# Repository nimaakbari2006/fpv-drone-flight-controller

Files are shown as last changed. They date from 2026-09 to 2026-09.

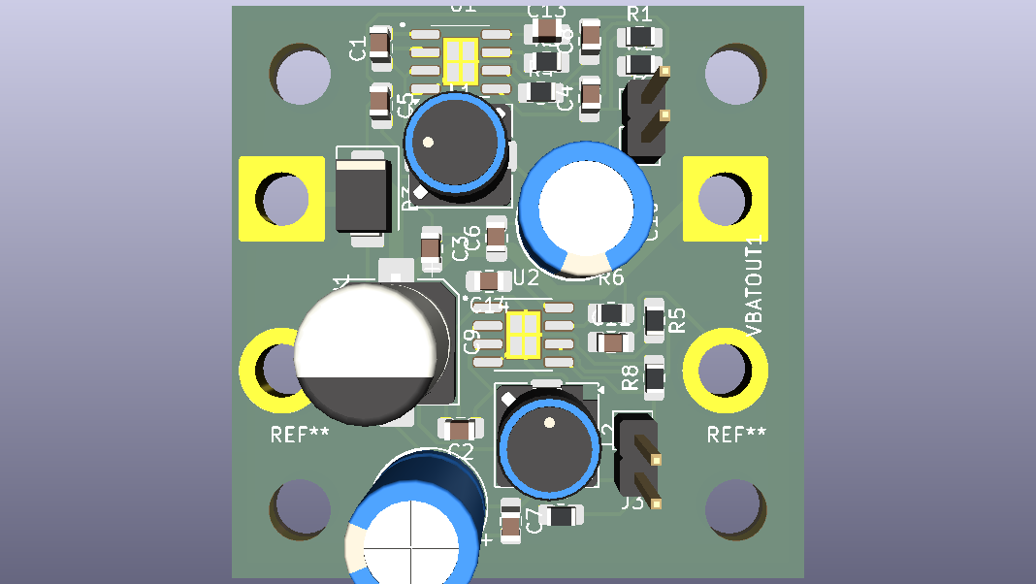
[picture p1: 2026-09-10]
PDB/PDB_layout.png.png

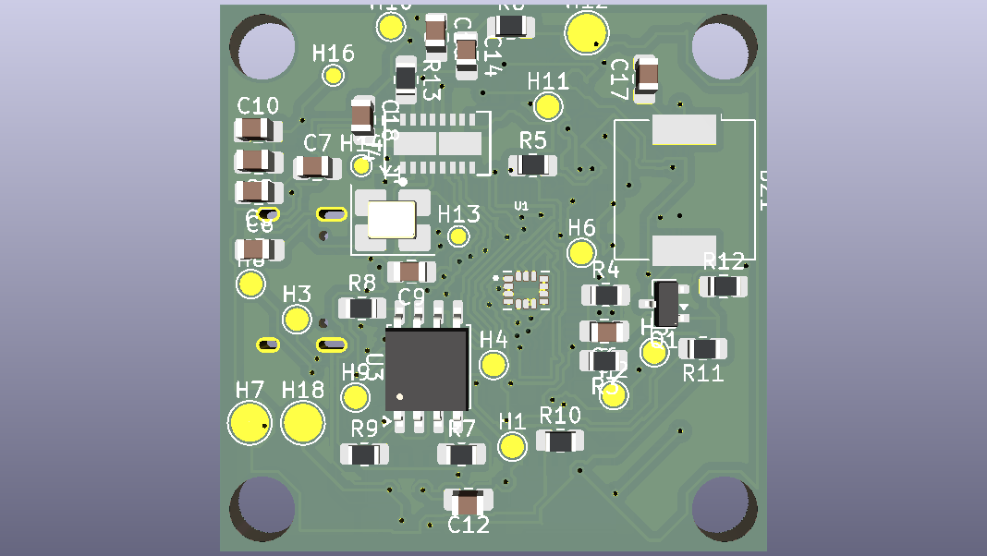
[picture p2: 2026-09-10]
FlightController/FCBOTTOMVIEW.png

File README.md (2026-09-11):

# Custom FPV Drone — Power Distribution Board & Flight Controller

Two custom PCBs designed from scratch in KiCad for a 5-inch FPV drone, plus complete component selection and compatibility validation for the full build. This project covers the full stack: switching power supply design, a Betaflight-compatible flight controller, and systems-level integration of the entire aircraft.

---

## Overview

The goal was to replace the stock electronics of a 5-inch FPV drone with custom-designed hardware, as an electrical engineering portfolio project. Two boards were designed:

1. **Power Distribution Board (PDB)** — takes 4S LiPo battery input and generates regulated 5V and 3.3V rails while distributing raw battery power to the ESC.
2. **Flight Controller (FC)** — an STM32F405-based, Betaflight-compatible flight controller with a full peripheral set.

Both boards were designed to the standard 30.5 × 30.5 mm FPV stack mounting pattern to integrate with the airframe and ESC.

---

## Power Distribution Board

A dual-output switching power supply feeding the drone's electronics.

**Key features:**
- 4S LiPo (up to ~16.8V) input with XT60 connection
- Two synchronous buck converters (MP2307) generating **5V** and **3.3V**
- Input protection: SM6T22A TVS diode against voltage spikes
- Raw battery pass-through (VBATOUT) to the 4-in-1 ESC via wide copper
- Feedback dividers, compensation networks, soft-start, and proper input/output decoupling on each channel

**Design decisions:**
- Chose the **MP2307 synchronous buck** over the older LM2596 after finding that the LM2596's through-hole inductors exceeded the frame's stack-height clearance — a real mechanical constraint that drove the part selection toward a smaller SMD synchronous design.
- Replaced the large through-hole bulk capacitor with an SMD polymer cap to fit the board within the mounting footprint.

*(See `/PDB/` for schematic, layout, 3D render, and Gerbers.)*

---

## Flight Controller

A full-featured, Betaflight-compatible flight controller.

**Core:**
- **STM32F405RGT6** MCU (LQFP-64)
- **ICM-42688-P** gyro/accelerometer over SPI1
- 8 MHz crystal, full power decoupling, VCAP, reset & boot circuitry
- USB-C for configuration and firmware flashing (with CC pulldowns and power-OR Schottky)
- Onboard 3.3V LDO so the board runs from USB alone on the bench

**Peripherals:**
- **AT7456E OSD** for on-screen display over the analog video feed (SPI3)
- **W25Q128 SPI flash** for blackbox flight logging
- 4 motor outputs (DShot-capable timer pins) + ESC telemetry & current sense
- ELRS receiver UART, VTX (SmartAudio) control, GPS UART
- Analog camera input and VTX video output through the OSD
- Battery voltage sensing, buzzer driver, addressable LED output
- SWD debug header

**Design decisions:**
- Followed the official **Betaflight F405 pin mapping** so the board matches an existing firmware target rather than requiring a custom one (gyro on SPI1, OSD/flash sharing SPI3, careful UART assignment to avoid the DFU/USART conflict).
- **4-layer stackup** with a dedicated internal ground plane beneath the IMU for clean gyro readings, and controlled routing of the USB differential pair.

*(See `/FlightController/` for schematic, layout, 3D render, and Gerbers.)*

---

## Circuit Design & Component Selection

The design methodology was datasheet-driven: each IC's manufacturer datasheet specifies a recommended application circuit, and following those recommended values — for decoupling, compensation, loop stability, and support components — is the correct engineering practice rather than guessing or reinventing them. Where the design required application-specific values that the datasheet does not give directly (chiefly the regulator output voltages and the battery-sense scaling), those were calculated from the relevant equations. This section documents both.

### Values sourced from datasheets and reference circuits

The majority of passive values came directly from the manufacturers' recommended application circuits:

- **MCU decoupling** — the STM32F405 datasheet specifies a **100 nF** ceramic at each VDD pin plus a shared bulk capacitor; the **2.2 µF** low-ESR capacitors on the VCAP core-regulator pins are a hard datasheet requirement (the internal core regulator will not start without them).
- **Analog supply filtering** — the **600 Ω @ 100 MHz** ferrite bead plus **1 µF / 100 nF** VDDA filter follows ST's recommended arrangement to keep digital switching noise off the ADC reference.
- **Buck converter support** — the MP2307's loop-compensation R–C network, **10 nF** soft-start capacitor, **10 nF** bootstrap capacitor, and input/output capacitor values were taken from the MP2307 datasheet's typical application circuit for the chosen inductor and output-cap combination.
- **IMU** — the ICM-42688-P's supply decoupling (**2.2 µF + 100 nF**) follows TDK's reference circuit, and its reserved pins were terminated exactly as the datasheet pin-description table specifies.
- **OSD** — the on-screen-display support components and crystal frequency were taken from the OSD device's datasheet and a known-good reference design.

Using the datasheet's recommended circuit is deliberate: manufacturers characterise these values for stability and noise performance, and deviating from them without reason is how power supplies end up oscillating or ICs end up unstable.

### Values calculated for this design

A few values are application-specific and were derived rather than copied:

**Buck converter output voltages (feedback dividers).** The MP2307 servos its feedback pin to an internal 0.925 V reference; the output is set by a divider:

```
Vout = 0.925 V × (1 + Rtop / Rbot)
```

With Rbot fixed at 10 kΩ, Rtop was solved for each rail:
- **5V rail:** Rtop ≈ 44.05 kΩ → nearest E96 value **44.2 kΩ** (gives 5.01 V)
- **3.3V rail:** Rtop ≈ 25.68 kΩ → nearest E96 value **25.5 kΩ** (gives 3.28 V)

1% (E96) resistors were used so output accuracy is set by the reference and divider, not resistor drift.

**Battery voltage sensing.** A **100 kΩ / 10 kΩ** divider scales the raw battery voltage down to the STM32's 3.3 V ADC range: at 4S full charge (16.8 V) the ADC sees ~1.5 V, at 6S (25.2 V) ~2.3 V — both safely under the 3.3 V limit with headroom. This matches Betaflight's default voltage-sensing scale.

**Crystal load capacitors.** Sized from the crystal's specified load capacitance and estimated board stray capacitance using `Cload_cap ≈ 2 × (CL − Cstray)`, giving **~22 pF** per oscillator node.

### Values set by standards

- **5.1 kΩ** pull-downs on the USB-C CC pins — the specific value required by the USB-C specification for a device to advertise itself and draw bus power.
- **75 Ω** termination on the analog video lines — matches the standard 75 Ω video signal impedance.

### Values from standard digital-design practice

Pull-ups and pull-downs were chosen high enough to draw negligible current but low enough to hold a defined logic level against pin leakage — **10 kΩ** for the NRST pull-up, BOOT0/BOOT1 pull-downs, and the SPI flash/OSD chip-select and hold lines; **100 kΩ** for the buzzer MOSFET gate pull-down so it stays off while its GPIO is floating during boot.

---

## Full Drone Build & Component Selection

Beyond the PCBs, the project involved specifying and validating an entire FPV drone, ensuring every component is electrically and mechanically compatible.

**Key selection decisions:**
- **Motors:** iFlight XING 2207 **1800KV** — the correct kV range for a 4S 5-inch freestyle build (higher-kV variants are 2–4S racing parts).
- **Video system:** a fully **analog 5.8GHz** chain — RunCam Robin 3 → JHEMCU VTX20-600 → FlyFishRC Osprey antenna → goggles — with **RHCP** polarization matched from drone to goggles.
- **Control link:** **ELRS 2.4GHz** (RadioMaster Pocket + Nano RX), both on FCC firmware for region compatibility.
- **ESC:** 55A rating, sized comfortably above the motors' ~35A peak draw.

**Interface & connector compatibility** (each verified against the actual component pinouts):
- FC ↔ ESC: 8-pin JST-SH (motor signals, telemetry, current, power)
- FC ↔ Camera: 6-pin JST-SH, wired to the RunCam Robin 3's pinout (power, GND, video, camera control)
- FC ↔ VTX: 4-pin (video, GND, battery, SmartAudio)
- FC ↔ GPS / Receiver: JST-SH UART connectors
- Video RF: MMCX (VTX to antenna), RHCP polarization matched throughout

*(See `/BOM/FPV_Drone_BOM.xlsx` for the complete bill of materials with compatibility notes.)*

---

## Tools & Skills

**KiCad** · schematic capture · PCB layout · 4-layer stackup design · switching power supply design · SPI/UART bus architecture · USB routing · DRC/ERC verification · library management (symbol/footprint import) · datasheet-driven design · systems integration · component selection & compatibility analysis

---

## Status

Both boards are fully designed and verified in KiCad (ERC and DRC clean). Manufacturing files (Gerbers, BOM, placement) generated for fabrication and assembly. Full drone build specified and components sourced.

*Physical assembly and flight testing to follow — this README will be updated with assembly photos and results.*

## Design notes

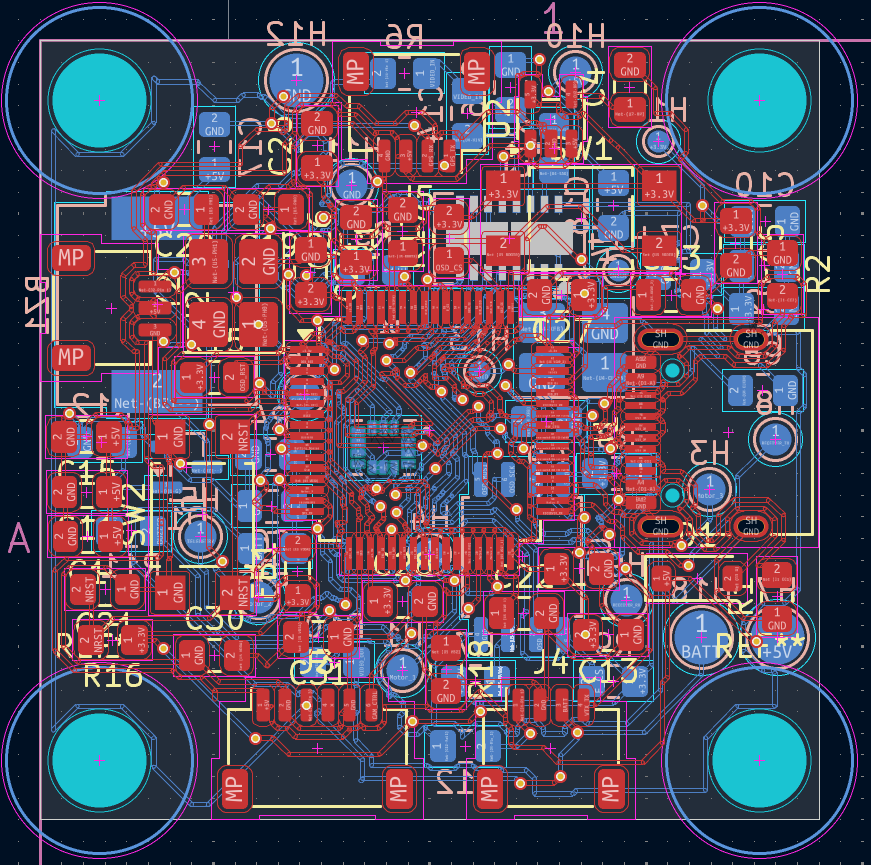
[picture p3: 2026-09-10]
FlightController/PCBLAYOUT.png

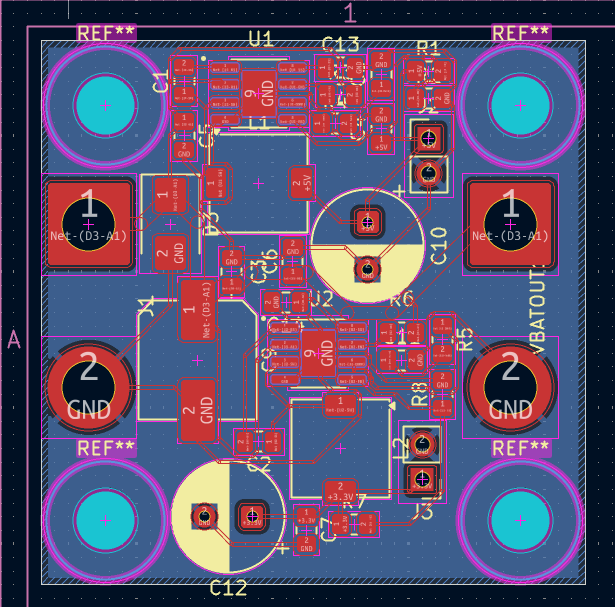
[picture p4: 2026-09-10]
PDB/PCBLAYOUT.png

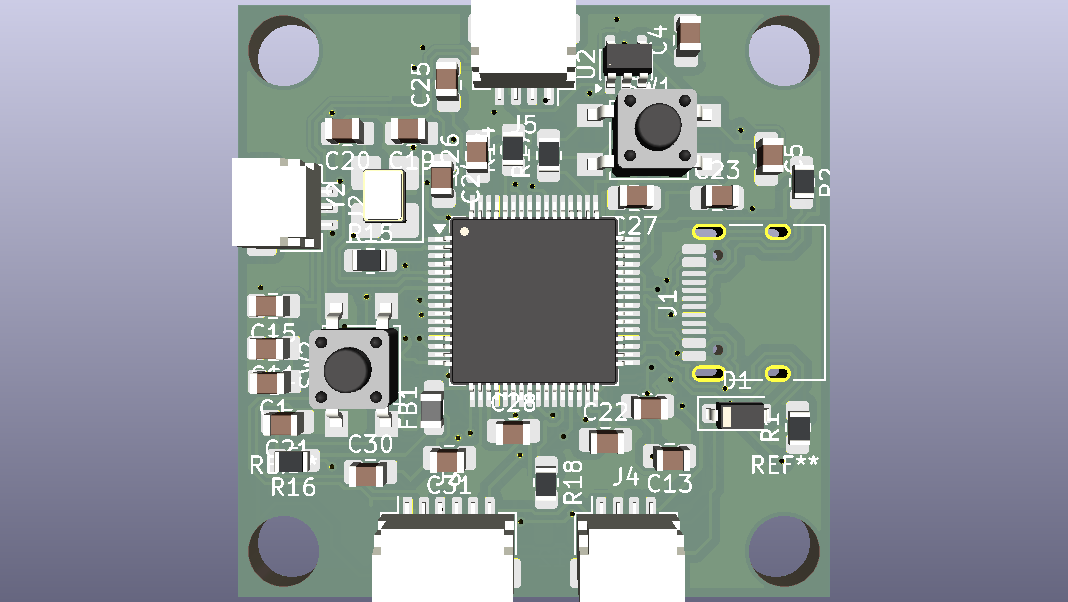
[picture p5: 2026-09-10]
FlightController/FCTOPVIEW.png

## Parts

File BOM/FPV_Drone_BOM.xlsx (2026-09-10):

FPV Drone — Complete Bill of Materials
5-inch Freestyle Build • Mark4 frame • 4S • Analog 5.8GHz FPV • ELRS 2.4GHz • Custom PDB + FC (in development)
MECHANICAL / AIRFRAME
Item | Chosen Part | Key Specs | Qty | Status | Cost (CAD) | Notes / Compatibility
Frame | Mark4 5-inch (REA-Mark-5), Red | 5" props, 2207 motors, 30.5×30.5 stack, 19.3mm cam mount | 1 | TO BUY | $29.82 | Aliexpress (https://www.aliexpress.com/item/1005007889232446.html?scm_id=1007.23125.137358.0&scm-url=1007.23125.137358.0)
Motors | iFlight XING-E Pro 2207 1800KV | 12N14P, 3–6S, 35A max, 16×16 mount | 4 | TO BUY | $82.53 | Aliexpress (https://www.aliexpress.com/item/1005007751330225.html?scm_id=1007.23125.137358.0&scm-url=1007.23125.137358.0)
Propellers | Gemfan 51466 V2 tri-blade, Midnight Gray | 5", M5 shaft, CW+CCW, 2207+ motors | 2 packs | TO BUY | $50.00 | Aliexpress (https://www.aliexpress.com/item/1005006320959638.html?scm_id=1007.23125.137358.0&scm-url=1007.23125.137358.0)
Battery straps | FlyFishRC strap | 20×250mm, metal buckle | 5PK 2SET | TO BUY | $20.00 | Aliexpress (https://www.aliexpress.com/item/1005010398663157.html?curPageLogUid=y0xrC8Tz6n97)
POWER / MOTOR SYSTEM
Item | Chosen Part | Key Specs | Qty | Status | Cost (CAD) | Notes / Compatibility
FC + ESC Stack | DAKEFPV F405 55A Stack | F405 MCU, 55A 4-in-1, 30.5×30.5, BLHeli_S, DShot | 1 | TO BUY | 62.38 | Aliexpress (https://www.aliexpress.com/item/1005012244392227.html?curPageLogUid=BF1mfSOBs0Lg)
↳ incl. 1000µF cap | 35V 1000µF Low-ESR | Battery bulk cap | 1 | TO BUY
↳ incl. cables/hardware | SH cables, grommets, screws, XT60 | FC-ESC cable, soft-mount, 70mm XT60 | set | TO BUY
Battery | Zeee 4S 1500mAh 120C | 14.8V, XT60, 120C, ~177g | 2-pk (+1 existing = 3) | TO BUY | $55.99 | Amazon (https://www.amazon.ca/Zeee-Graphene-Quadcopter-Helicopter-Airplane/dp/B0868RDZZP)
XT60 spares (custom PDB) | XT60 pigtails | For testing your custom PDB later | — | Optional
CONTROL / RADIO LINK
Item | Chosen Part | Key Specs | Qty | Status | Cost (CAD) | Notes / Compatibility
Radio (handset) | RadioMaster Pocket | ELRS 2.4GHz, FCC, Mode 2, EdgeTX | 1 | TO BUY | $136.40 | FCC = correct for Canada; ELRS matches receiver
Receiver | RadioMaster Nano ELRS 2.4GHz | ELRS 2.4GHz, CRSF, 5V | 1 | TO BUY |  | INCLUDED with radio — FCC-matched, no separate buy
↳ incl. 18650 cells | 2× 18650 | Powers the radio | 2 | TO BUY |  | Included in radio bundle
VIDEO SYSTEM — TRANSMIT (on drone)
Item | Chosen Part | Key Specs | Qty | Status | Cost (CAD) | Notes / Compatibility
FPV Camera | RunCam Robin 3 | Analog, 1200TVL, 4:3, 19mm, 5-23V | 1 | TO BUY | $16.08 | Analog; 19mm fits 19.3mm mount; powers from stack
VTX | JHEMCU VTX20-600 | 5.8GHz analog, 40CH, PIT-600mW, MMCX, 5V BEC | 1 | TO BUY | $24.09 | 600mW proper power; MMCX matches antenna
Drone Antenna | FlyFishRC Osprey | 5.8GHz, MMCX, RHCP, 90mm | 1 | TO BUY | $8.93 | MMCX matches VTX; RHCP sets system polarization
VIDEO SYSTEM — RECEIVE (goggles)
Item | Chosen Part | Key Specs | Qty | Status | Cost (CAD) | Notes / Compatibility
FPV Goggles | Mini FPV Goggles (box) | Analog 5.8GHz, 40CH all bands, 3" 480×320, <20ms | 1 | TO BUY | 90.67 | Analog matches system; RP-SMA antennas
Goggle Antennas (upgrade) | RP-SMA RHCP cloverleaf | 5.8GHz, RHCP, RP-SMA | pair | Optional
CHARGING
Item | Chosen Part | Key Specs | Qty | Status | Cost (CAD) | Notes / Compatibility
Charger | iMAX B6 | Balance, 1-6S LiPo, 0.1-6A, 80W | 1 | Ordered | 45.77
Power Supply | 12V 5A AC adapter | 60W, powers the B6 | 1 | Ordered |  | 60W ample for 4S 1500mAh charging
Charge Lead | Banana-to-XT60 lead | Connects battery to charger | 1 | Ordered |  | Required to connect XT60 packs to B6
SAFETY / CONSUMABLES
Item | Chosen Part | Key Specs | Qty | Status | Cost (CAD) | Notes / Compatibility
LiPo Safety Bag | Fireproof LiPo bag | Charge & store LiPos inside | 1 | TO BUY
Spare props | Gemfan 51466 V2 | Restock as you break them | — | Later
CUSTOM PCBs (your resume project — in development)
Item | Chosen Part | Key Specs | Qty | Status | Cost (CAD) | Notes / Compatibility
Custom PDB | Your KiCad design | Dual MP2307 buck, 5V+3.3V, TVS, 40×40mm | 1 | Ordered |  | component ordered
Custom FC | Your KiCad design (F405) | STM32F405, ICM-42688-P, USB-C, OSD, etc. | 1 | Ordered |  | component ordered
PCB fabrication | JLCPCB / PCBWay | 2× boards, ~5 pcs each | — | Ordered |  | component ordered
PCB components | STM32, IMU, MP2307×2, passives | BOM from KiCad | — | TO DO
TOOLS (one-time, for assembly & PCB work)
Item | Chosen Part | Key Specs | Qty | Status | Cost (CAD) | Notes / Compatibility
Soldering iron | Temp-controlled (e.g. Pinecil V2) | For assembly + PCB | 1 | TO BUY
Hot air station | For QFN/fine-pitch (FC assembly) | Needed for IMU/MCU QFN | 1 | TO BUY
Consumables | Solder, flux, wick, tweezers, IPA, microscope | SMD soldering kit | set | TO BUY
SMD practice kit | Cheap practice board | Learn before touching real boards | 1 | TO BUY
TRACKED SPEND SO FAR (items with recorded prices) |  |  |  |  | $622.66 | Excludes: stack, goggles, charger, LiPo bag, PCBs, tools (prices not logged)

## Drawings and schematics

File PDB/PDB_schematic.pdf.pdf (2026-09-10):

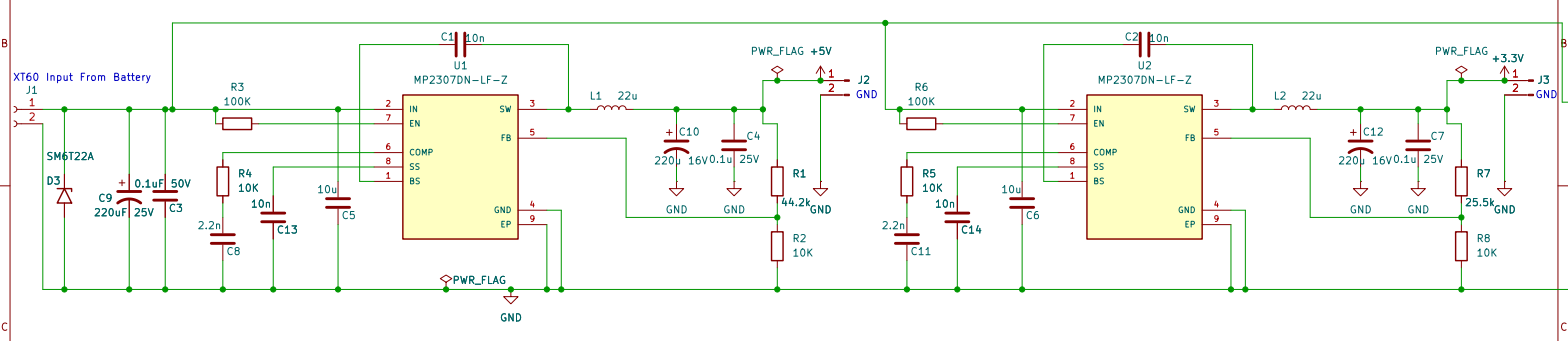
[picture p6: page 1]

Size: A4 | Rev:
KiCad E.D.A. 10.0.1 | Id: 1/1

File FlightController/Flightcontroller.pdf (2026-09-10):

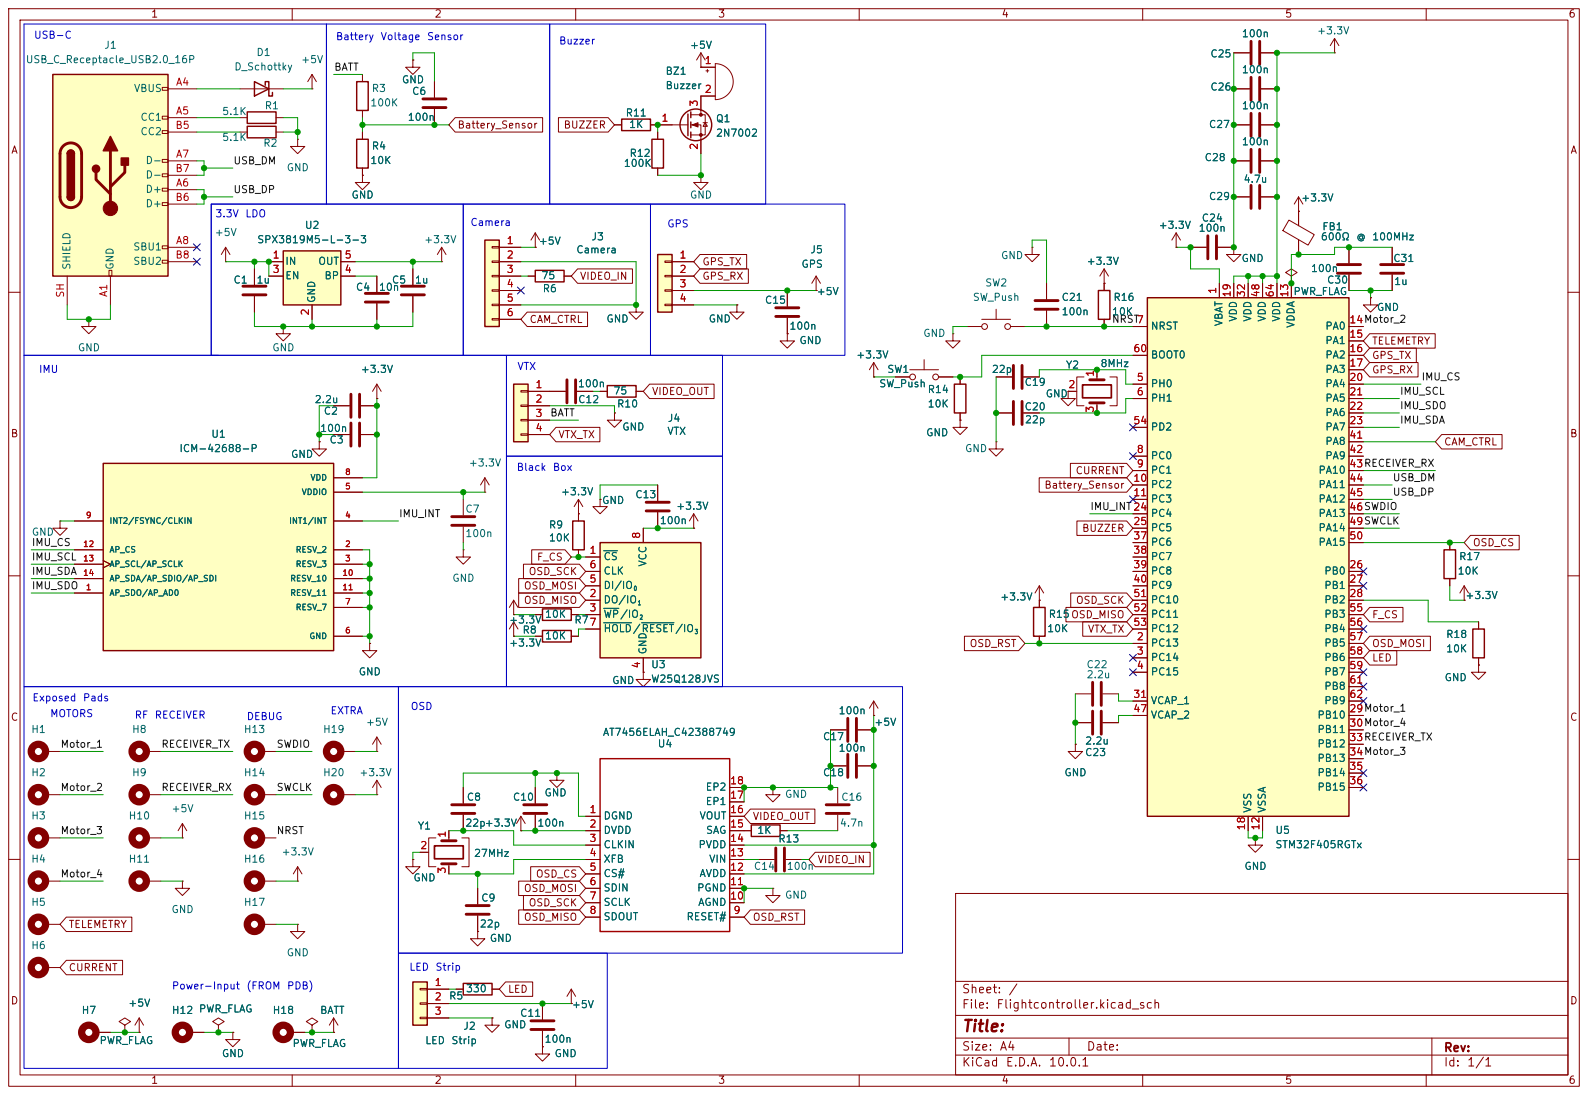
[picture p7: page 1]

4 DI/IO0 5 CLK 6 HOLD/RESET/IO3 7 VCC

AGND 10 PGND 11 AVDD 12 VIN 13 PVDD 14 SAG 15 VOUT 16 EP1 17 EP2 18 U4

Power-Input (FROM PDB)

Size: A4 | Rev:
KiCad E.D.A. 10.0.1 | Id: 1/1

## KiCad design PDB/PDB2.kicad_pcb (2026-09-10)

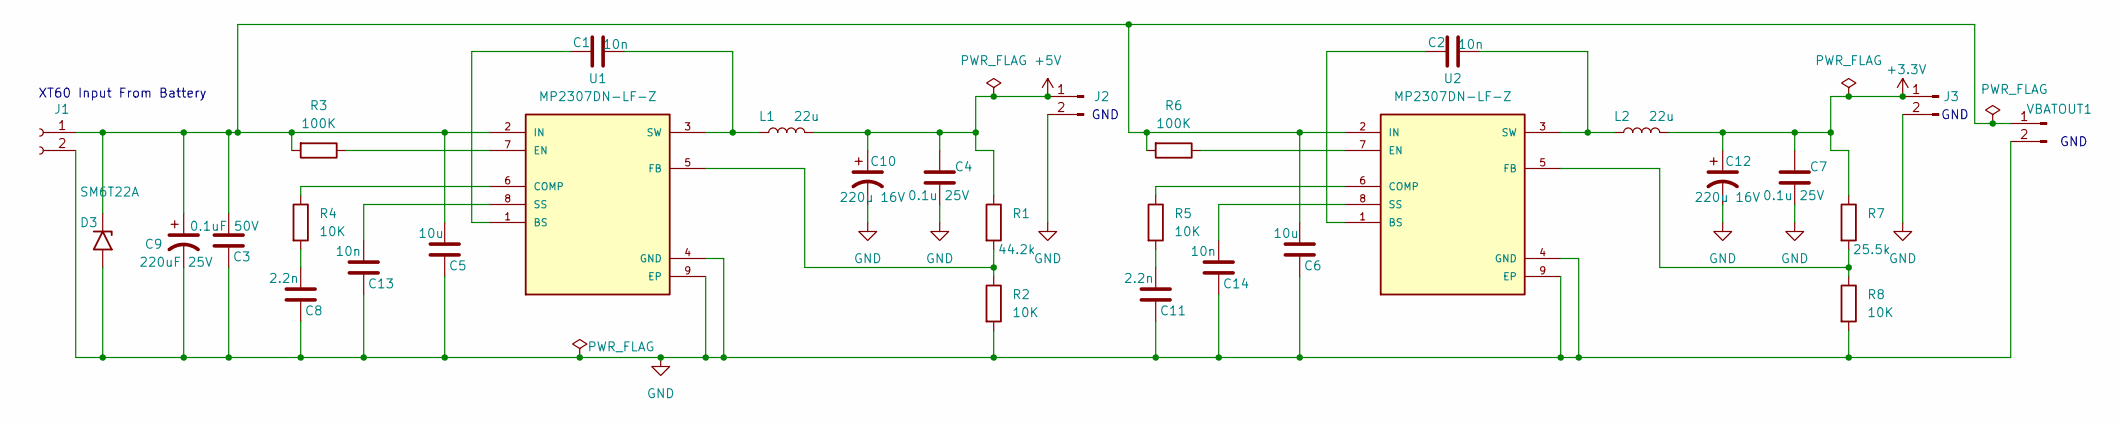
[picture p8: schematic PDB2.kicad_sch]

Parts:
C1, C2, C13, C14: 10n; C_0805_2012Metric_Pad1.18x1.45mm_HandSolder
C3: 0.1uF 50V; C_0805_2012Metric_Pad1.18x1.45mm_HandSolder
C4, C7: 0.1u 25V; C_0805_2012Metric_Pad1.18x1.45mm_HandSolder
C5, C6: 10u; C_0805_2012Metric_Pad1.18x1.45mm_HandSolder
C8, C11: 2.2n; C_0805_2012Metric_Pad1.18x1.45mm_HandSolder
C9: 220uF 25V; CP_Elec_8x10.5
C10, C12: 220u 16V; CP_Radial_D8.0mm_P3.50mm
D3: SM6T22A; D_SMB
J1: Conn_01x02_Socket; SolderWire-4sqmm_1x02_P12mm_D3mm_OD6mm
J2, J3: Conn_01x02_Pin; PinHeader_1x02_P2.54mm_Vertical
L1, L2: 22u; L_TDK_SLF7045
R1: 44.2k; R_0805_2012Metric_Pad1.20x1.40mm_HandSolder
R2, R4, R5, R8: 10K; R_0805_2012Metric_Pad1.20x1.40mm_HandSolder
R3, R6: 100K; R_0805_2012Metric_Pad1.20x1.40mm_HandSolder
R7: 25.5k; R_0805_2012Metric_Pad1.20x1.40mm_HandSolder
U1, U2: MP2307DN-LF-Z; SOIC127P600X170-9N; PARTREV 1.9; DigiKey_Part_Number 1589-1576-1-ND
VBATOUT1: Conn_01x02_Pin; SolderWire-4sqmm_1x02_P12mm_D3mm_OD6mm

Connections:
+3.3V: C7.1, C12.1, J3.1, L2.2, R7.1
+5V: C4.1, C10.1, J2.1, L1.2, R1.1
GND: C3.2, C4.2, C5.2, C6.2, C7.2, C8.2, C9.2, C10.2, C11.2, C12.2, C13.2, C14.2, D3.2 (A2), J1.2, J2.2, J3.2, R2.2, R8.2, U1.4 (GND), U1.9 (EP), U2.4 (GND), U2.9 (EP), VBATOUT1.2
unnamed: C8.1, R4.2
unnamed: C11.1, R5.2
unnamed: C3.1, C5.1, C6.1, C9.1, D3.1 (A1), J1.1, R3.2, R6.2, U1.2 (IN), U2.2 (IN), VBATOUT1.1
unnamed: C1.2, U1.1 (BS)
unnamed: R4.1, U1.6 (COMP)
unnamed: R3.1, U1.7 (EN)
unnamed: R1.2, R2.1, U1.5 (FB)
unnamed: C13.1, U1.8 (SS)
unnamed: C1.1, L1.1, U1.3 (SW)
unnamed: C2.2, U2.1 (BS)
unnamed: R5.1, U2.6 (COMP)
unnamed: R6.1, U2.7 (EN)
unnamed: R7.2, R8.1, U2.5 (FB)
unnamed: C14.1, U2.8 (SS)
unnamed: C2.1, L2.1, U2.3 (SW)

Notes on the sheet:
XT60 Input From Battery
GND

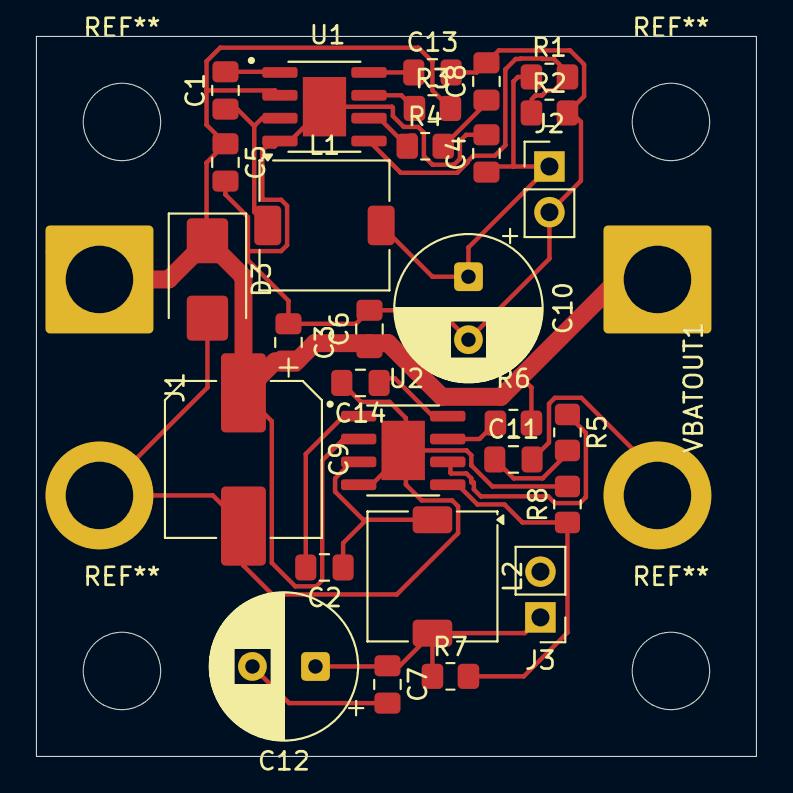
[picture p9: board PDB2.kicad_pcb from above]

Board: 2 copper layers, 40.0 x 40.0 mm, 31 parts (0 on the bottom side), 18 nets.

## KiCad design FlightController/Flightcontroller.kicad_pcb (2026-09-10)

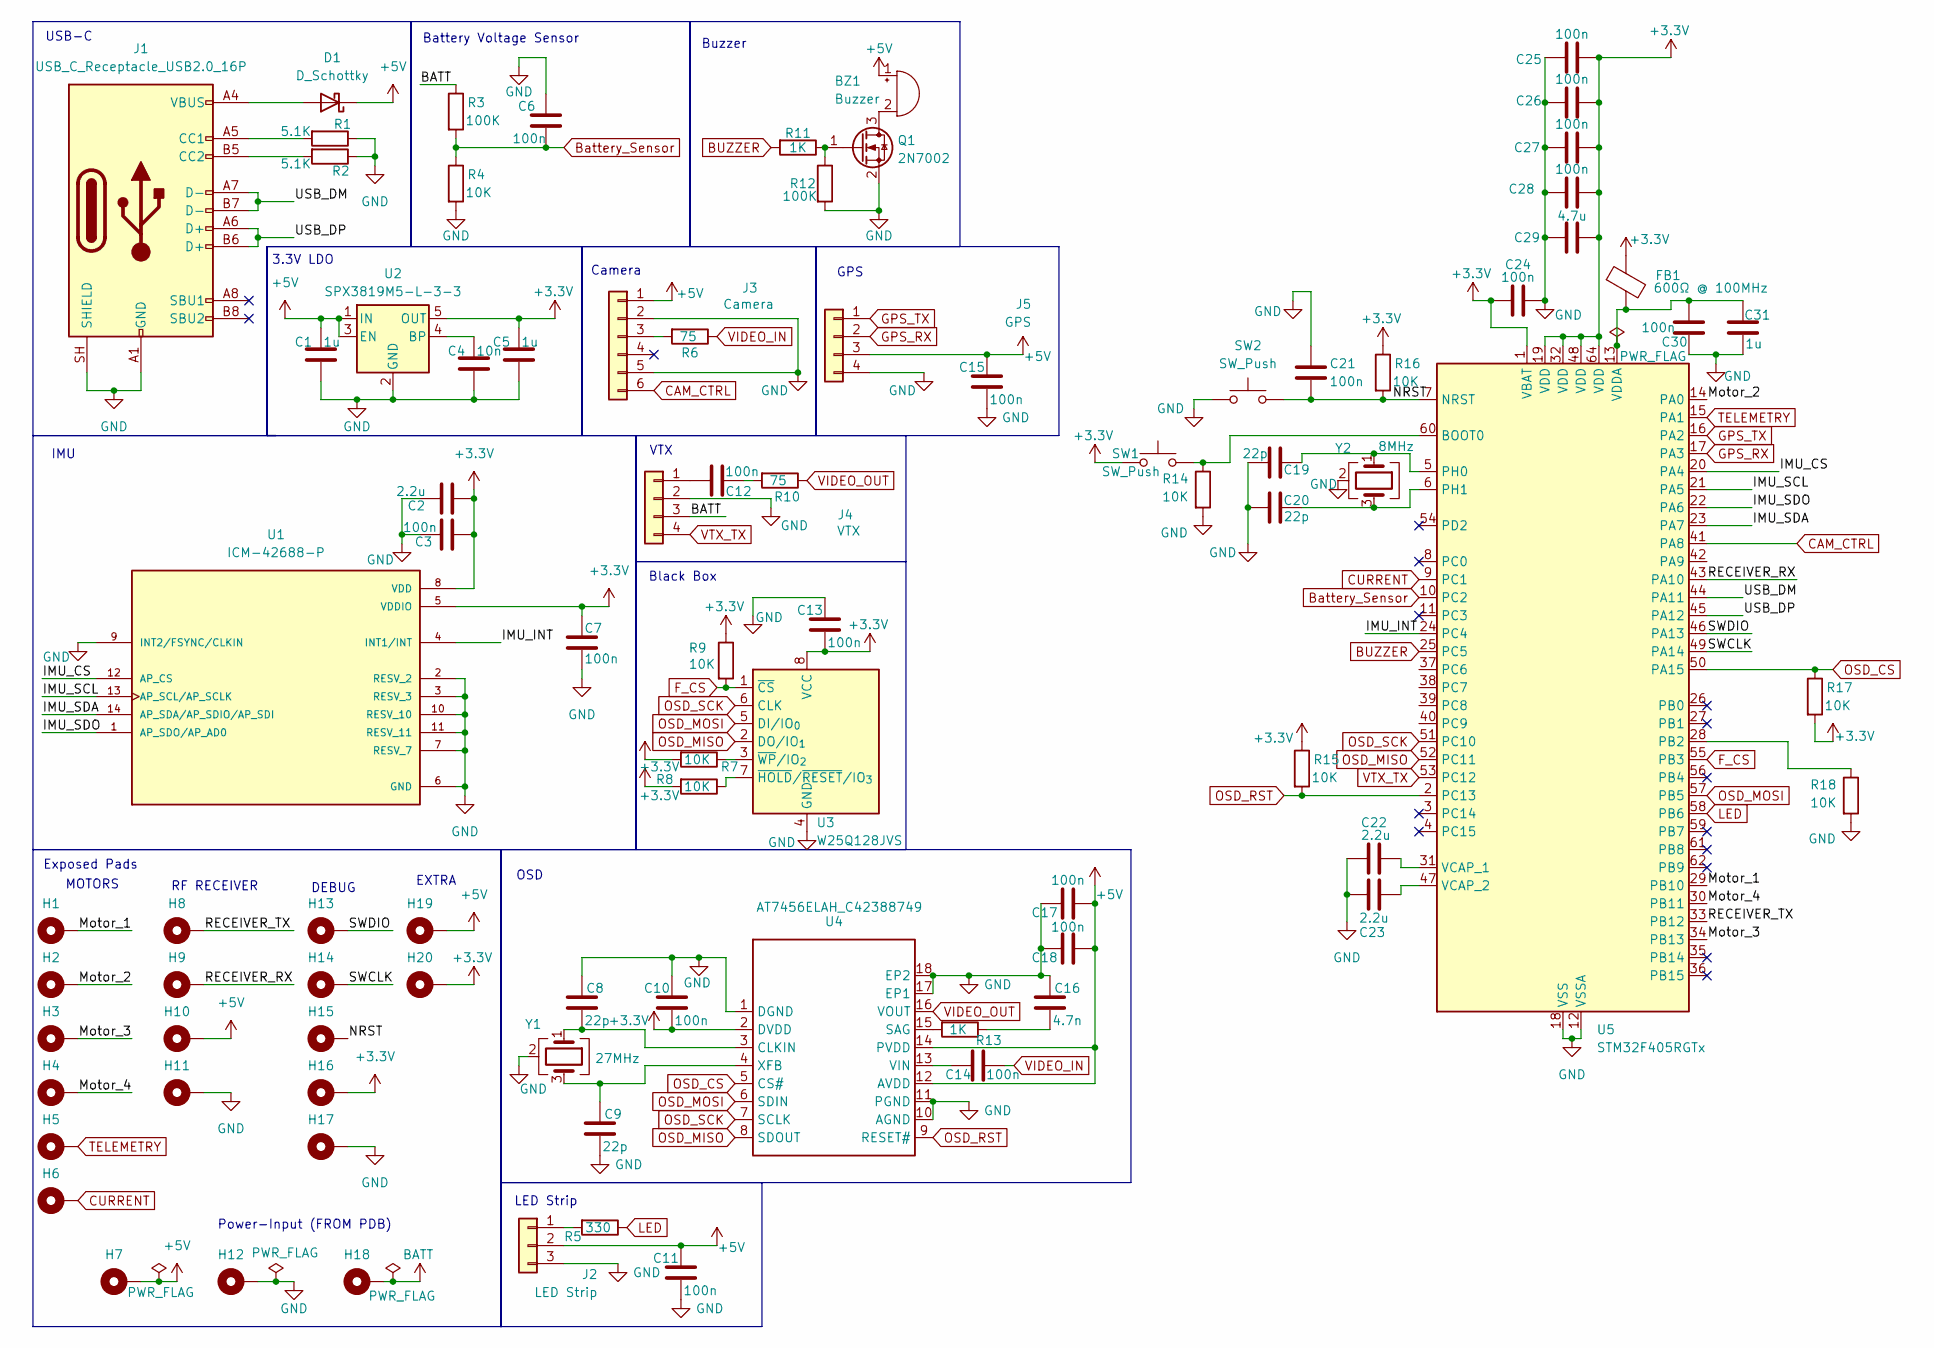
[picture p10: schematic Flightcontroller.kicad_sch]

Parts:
BZ1: Buzzer; Buzzer_CUI_CPT-9019S-SMT
C1, C5, C31: 1u; C_0805_2012Metric_Pad1.18x1.45mm_HandSolder
C2, C22, C23: 2.2u; C_0805_2012Metric_Pad1.18x1.45mm_HandSolder
C3, C6, C7, C10, C11, C12, C13, C14, C15, C17, C18, C21, C24, C25, C26, C27, C28, C30: 100n; C_0805_2012Metric_Pad1.18x1.45mm_HandSolder
C4: 10n; C_0805_2012Metric_Pad1.18x1.45mm_HandSolder
C8, C9, C19, C20: 22p; C_0805_2012Metric_Pad1.18x1.45mm_HandSolder
C16: 4.7n; C_0805_2012Metric_Pad1.18x1.45mm_HandSolder
C29: 4.7u; C_0805_2012Metric_Pad1.18x1.45mm_HandSolder
D1: D_Schottky; D_SOD-123
FB1: 600Ω @ 100MHz; L_0805_2012Metric_Pad1.05x1.20mm_HandSolder
H1: Motor_1; TestPoint_Pad_D1.5mm
H2: Motor_2; TestPoint_Pad_D1.5mm
H3: Motor_3; TestPoint_Pad_D1.5mm
H4: Motor_4; TestPoint_Pad_D1.5mm
H5: TELEMETRY; TestPoint_Pad_D1.5mm
H6: CURRENT; TestPoint_Pad_D1.5mm
H7: 5V; TestPoint_Pad_D2.5mm
H8: RECEIVER_TX; TestPoint_Pad_D1.5mm
H9: RECEIVER_RX; TestPoint_Pad_D1.5mm
H10: 5V; TestPoint_Pad_D1.5mm
H11: GND; TestPoint_Pad_D1.5mm
H12: GND; TestPoint_Pad_D2.5mm
H13: SWDIO; TestPoint_Pad_D1.0mm
H14: SWCLK; TestPoint_Pad_D1.0mm
H15: NRST; TestPoint_THTPad_D2.0mm_Drill1.0mm
H16: 3.3V; TestPoint_Pad_D1.0mm
H17: GND; TestPoint_THTPad_D2.0mm_Drill1.0mm
H18: BATT; TestPoint_Pad_D2.5mm
H19: 5V; TestPoint_THTPad_D2.0mm_Drill1.0mm
H20: 3.3V; TestPoint_THTPad_D2.0mm_Drill1.0mm
J1: USB_C_Receptacle_USB2.0_16P; USB_C_Receptacle_HRO_TYPE-C-31-M-12
J2: LED Strip; JST_SH_SM03B-SRSS-TB_1x03-1MP_P1.00mm_Horizontal
J3: Camera; JST_SH_SM06B-SRSS-TB_1x06-1MP_P1.00mm_Horizontal
J4: VTX; JST_SH_SM04B-SRSS-TB_1x04-1MP_P1.00mm_Horizontal
J5: GPS; JST_SH_SM04B-SRSS-TB_1x04-1MP_P1.00mm_Horizontal
Q1: 2N7002; SOT-23
R1, R2: 5.1K; R_0805_2012Metric_Pad1.20x1.40mm_HandSolder
R3, R12: 100K; R_0805_2012Metric_Pad1.20x1.40mm_HandSolder
R4, R7, R8, R9, R14, R15, R16, R17, R18: 10K; R_0805_2012Metric_Pad1.20x1.40mm_HandSolder
R5: 330; R_0805_2012Metric_Pad1.20x1.40mm_HandSolder
R6, R10: 75; R_0805_2012Metric_Pad1.20x1.40mm_HandSolder
R11, R13: 1K; R_0805_2012Metric_Pad1.20x1.40mm_HandSolder
SW1, SW2: SW_Push; SW_SPST_TL3305A
U1: ICM-42688-P; PQFN50P300X250X97-14N; PARTREV 1.2
U2: SPX3819M5-L-3-3; SOT-23-5
U3: W25Q128JVS; SOIC-8_5.3x5.3mm_P1.27mm
U4: AT7456ELAH_C42388749; LGA-16_L6.8-W4.0-P0.65-TL-2EP
U5: STM32F405RGTx; LQFP-64_10x10mm_P0.5mm
Y1: 27MHz; Crystal_SMD_3225-4Pin_3.2x2.5mm_HandSoldering
Y2: 8MHz; Crystal_SMD_3225-4Pin_3.2x2.5mm_HandSoldering

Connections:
+3.3V: C2.1, C3.1, C5.1, C7.1, C10.2, C13.2, C24.2, C25.1, C26.1, C27.1, C28.1, C29.1, FB1.1, H16.1 (1_1), H20.1, R7.2, R8.2, R9.1, R15.1, R16.1, R17.2, SW1.1, U1.5 (VDDIO), U1.8 (VDD), U2.5 (OUT), U3.8 (VCC), U4.2 (DVDD), U5.1 (VBAT), U5.19 (VDD), U5.32 (VDD), U5.48 (VDD), U5.64 (VDD)
+5V: BZ1.1 (+), C1.1, C11.1, C15.1, C17.1, C18.1, D1.1 (K), H7.1 (1_1), H10.1 (1_1), H19.1, J2.2, J3.1, J5.3, U2.1 (IN), U2.3 (EN), U4.12 (AVDD), U4.14 (PVDD)
/IMU_CS: U1.12 (AP_CS), U5.20 (PA4)
/IMU_INT: U1.4 (INT1/INT), U5.24 (PC4)
/IMU_SCL: U1.13 (AP_SCL/AP_SCLK), U5.21 (PA5)
/IMU_SDA: U1.14 (AP_SDA/AP_SDIO/AP_SDI), U5.23 (PA7)
/IMU_SDO: U1.1 (AP_SDO/AP_AD0), U5.22 (PA6)
/Motor_1: H1.1 (1_1), U5.29 (PB10)
/Motor_2: H2.1 (1_1), U5.14 (PA0)
/Motor_3: H3.1 (1_1), U5.34 (PB13)
/Motor_4: H4.1 (1_1), U5.30 (PB11)
/NRST: C21.2, H15.1, R16.2, SW2.2, U5.7 (NRST)
/RECEIVER_RX: H9.1 (1_1), U5.43 (PA10)
/RECEIVER_TX: H8.1 (1_1), U5.33 (PB12)
/SWCLK: H14.1 (1_1), U5.49 (PA14)
/SWDIO: H13.1 (1_1), U5.46 (PA13)
/USB_DM: J1.A7 (D-), J1.B7 (D-), U5.44 (PA11)
/USB_DP: J1.A6 (D+), J1.B6 (D+), U5.45 (PA12)
BATT: H18.1 (1_1), J4.3, R3.1
BUZZER: R11.2, U5.25 (PC5)
Battery_Sensor: C6.2, R3.2, R4.1, U5.10 (PC2)
CAM_CTRL: J3.6, U5.41 (PA8)
CURRENT: H6.1 (1_1), U5.9 (PC1)
F_CS: R9.2, U3.1 (~CS), U5.55 (PB3)
GND: C1.2, C2.2, C3.2, C4.2, C5.2, C6.1, C7.2, C8.1, C9.2, C10.1, C11.2, C13.1, C15.2, C16.1, C17.2, C18.2, C19.2, C20.2, C21.1, C22.2, C23.2, C24.1, C25.2, C26.2, C27.2, C28.2, C29.2, C30.1, C31.1, H11.1 (1_1), H12.1 (1_1), H17.1, J1.A1 (GND), J1.A12 (GND), J1.B1 (GND), J1.B12 (GND), J1.SH (SHIELD), J2.3, J3.2, J3.5, J4.2, J5.4, Q1.2 (S), R1.1, R2.1, R4.2, R12.2, R14.2, R18.2, SW2.1, U1.2 (RESV_2), U1.3 (RESV_3), U1.6 (GND), U1.7 (RESV_7), U1.9 (INT2/FSYNC/CLKIN), U1.10 (RESV_10), U1.11 (RESV_11), U2.2 (GND), U3.4 (GND), U4.1 (DGND), U4.10 (AGND), U4.11 (PGND), U4.17 (EP1), U4.18 (EP2), U5.12 (VSSA), U5.18 (VSS), U5.63 (VSS), Y1.2 (G), Y1.4 (G), Y2.2 (G), Y2.4 (G)
GPS_RX: J5.2, U5.17 (PA3)
GPS_TX: J5.1, U5.16 (PA2)
LED: R5.1, U5.58 (PB6)
unnamed: BZ1.2 (-), Q1.3 (D)
unnamed: C12.1, R10.2
unnamed: C16.2, R13.1
unnamed: D1.2 (A), J1.A4 (VBUS), J1.A9 (VBUS), J1.B4 (VBUS), J1.B9 (VBUS)
unnamed: J1.A5 (CC1), R1.2
unnamed: J1.B5 (CC2), R2.2
unnamed: J2.1, R5.2
unnamed: J3.3, R6.2
unnamed: C12.2, J4.1
unnamed: Q1.1 (G), R11.1, R12.1
unnamed: C4.1, U2.4 (BP)
unnamed: R8.1, U3.7 (~HOLD/~RESET/IO_{3})
unnamed: R7.1, U3.3 (~WP/IO_{2})
unnamed: C8.2, U4.3 (CLKIN), Y1.1
unnamed: R13.2, U4.15 (SAG)
unnamed: C14.2, U4.13 (VIN)
unnamed: C9.1, U4.4 (XFB), Y1.3
unnamed: R14.1, SW1.2, U5.60 (BOOT0)
unnamed: R18.1, U5.28 (PB2)
unnamed: C19.1, U5.5 (PH0), Y2.1
unnamed: C20.1, U5.6 (PH1), Y2.3
unnamed: C22.1, U5.31 (VCAP_1)
unnamed: C23.1, U5.47 (VCAP_2)
unnamed: C30.2, C31.2, FB1.2, U5.13 (VDDA)
OSD_CS: R17.1, U4.5 (CS#), U5.50 (PA15)
OSD_MISO: U3.2 (DO/IO_{1}), U4.8 (SDOUT), U5.52 (PC11)
OSD_MOSI: U3.5 (DI/IO_{0}), U4.6 (SDIN), U5.57 (PB5)
OSD_RST: R15.2, U4.9 (RESET#), U5.2 (PC13)
OSD_SCK: U3.6 (CLK), U4.7 (SCLK), U5.51 (PC10)
TELEMETRY: H5.1 (1_1), U5.15 (PA1)
VIDEO_IN: C14.1, R6.1
VIDEO_OUT: R10.1, U4.16 (VOUT)
VTX_TX: J4.4, U5.53 (PC12)

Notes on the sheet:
MOTORS
IMU
RF RECEIVER
VTX
Battery Voltage Sensor
Buzzer
Power-Input (FROM PDB)
LED Strip
3.3V LDO
Black Box
USB-C
DEBUG
Exposed Pads
EXTRA
GPS
Camera
OSD

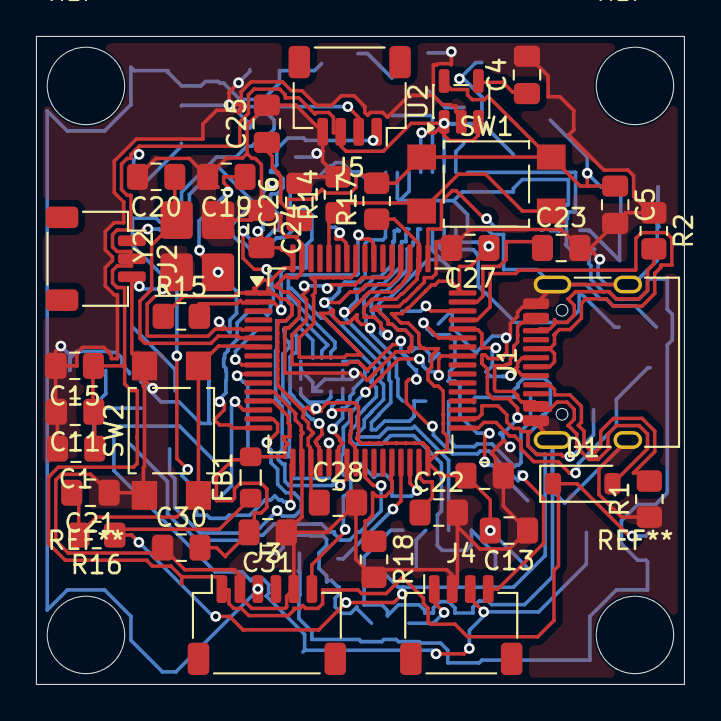
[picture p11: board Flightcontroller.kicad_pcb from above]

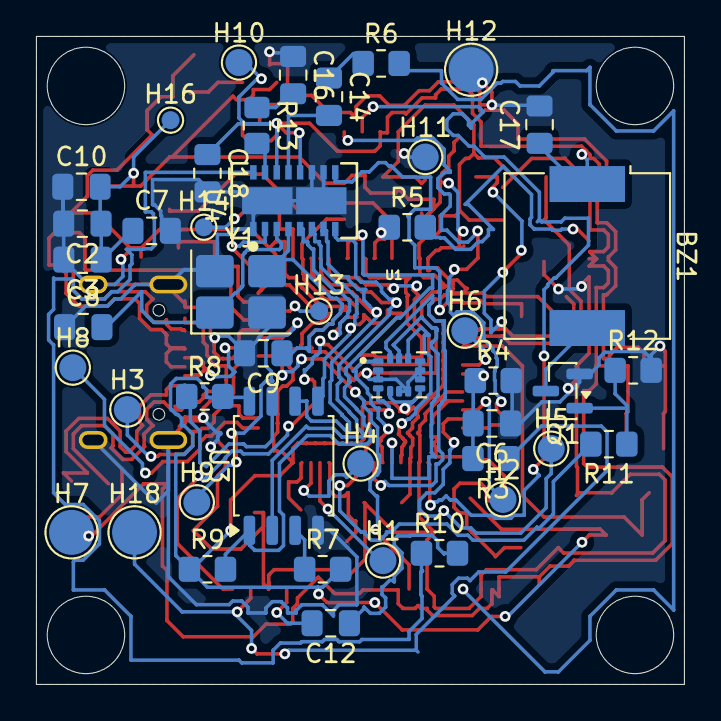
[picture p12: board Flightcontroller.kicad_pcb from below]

Board: 4 copper layers, 36.0 x 36.0 mm, 83 parts (45 on the bottom side), 61 nets.
